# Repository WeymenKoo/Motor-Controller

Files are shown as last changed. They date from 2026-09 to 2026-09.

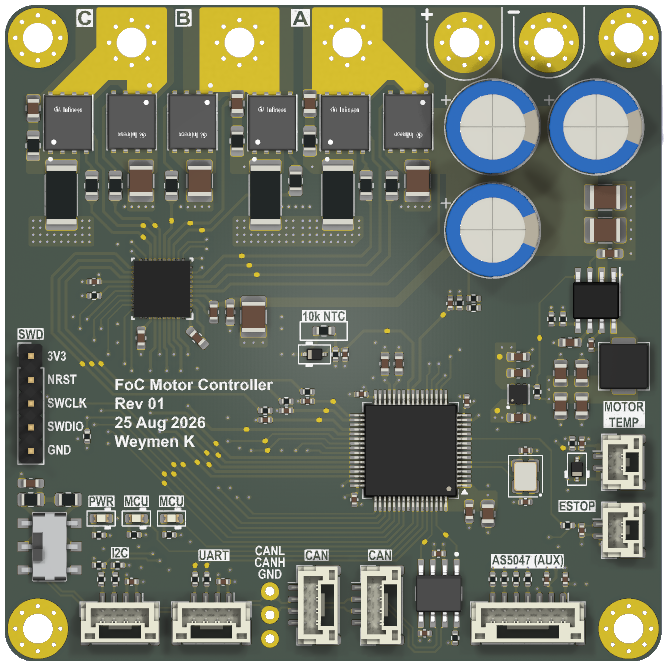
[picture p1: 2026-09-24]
Documentation/FoC Motor Controller Top.png

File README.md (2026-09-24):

# Building a FOC Motor Controller for a Cat-Scale Robot Leg

Technical notes from a full design cycle: idea → theory → schematic → simulation → layout → fab → bring-up plan. Written as a knowledge refresher as much as a build log, so each section starts with the background needed to follow the decision.

**Status:** Rev 1 design-frozen and fabricated. Not yet bench-validated. Everything below is analytical or derived from the fabrication files.

## Repository layout

| Path | Contents |
|---|---|
| `FoC Motor Controller.kicad_pro` / `.kicad_sch` / `.kicad_pcb` | KiCad 10 project, root sheet and board |
| `Schematics/` | Hierarchical sheets (power, MCU, gate driver, MOSFETs, sensing, CAN-FD, interconnects, ...) |
| `Libraries/` | Project-local symbols, footprints and 3D models (referenced via `${KIPRJMOD}/Libraries/`) |
| `Documentation/` | Design rationale, layout/manufacturing review, board renders, RevC action summary |
| `Simulation/` | LTspice inrush and inverter/gate-drive benches |
| `Project Outputs/` | BOM, pick-and-place, netlist, fabrication package (Rev 1), schematic PDF |

Open `FoC Motor Controller.kicad_pro` in KiCad 10. Vendor datasheets and the KiCad worksheet templates are not included in this repo; without the templates KiCad falls back to its default title block.

---

## 1. What and why

A single-axis field-oriented-control motor controller for one joint of a cat-scale bipedal robot. Six boards, one per joint, sharing a 12S bus, coordinated over CAN-FD.

The actuator architecture is **quasi-direct drive** — a low gear ratio (roughly 6:1 to 10:1) between a large-diameter pancake outrunner and the joint, rather than the 100:1+ of a conventional servo.

Why that matters, because it drives everything downstream:

| QDD property | Consequence for the electronics |
|---|---|
| Backdrivable, low reflected inertia | Torque control fidelity matters more than peak power. Current-sense accuracy becomes a first-class requirement, not an afterthought. |
| Joint torque ∝ motor current, almost directly | Current sense error *is* torque error. No gearbox to hide it behind. |
| Impacts transmit straight back to the motor | Regeneration is routine, not exceptional. Bus transient behaviour is a safety question. |
| It hangs on a limb | Board mass is a real constraint. An over-specified power stage is a defect, not free margin. |

Reference motor: ODrive M8325s, 100 KV, 92 mm pancake outrunner, **20 pole pairs**. That pole count comes back repeatedly.

---

## 2. Theory refresher: why FOC at all

### 2.1 The problem with six-step commutation

Trapezoidal (six-step) BLDC control energises two phases at a time and commutates on Hall transitions. It's simple, and for a fan or a drill it's fine. It has two properties that kill it for a leg joint:

- **Torque ripple.** Torque varies by roughly 13% across each 60° electrical sector because the current vector jumps in discrete steps rather than rotating smoothly.
- **No control of the current *angle*.** You can only control magnitude.

### 2.2 What FOC actually does

FOC transforms the three phase currents into a rotating reference frame locked to the rotor, so that a spinning three-phase AC problem becomes two DC quantities you can put a PI loop around.

```
Clarke:  3-phase (a,b,c)  →  2-axis stationary (α,β)
Park:    stationary (α,β) →  rotor-synchronous (d,q)   [needs rotor angle θ]

  i_d  = flux-producing current   → command 0 for a surface-PM motor
  i_q  = torque-producing current → this is your torque command
```

Two consequences worth internalising:

1. **Park needs θ.** The whole scheme collapses without an accurate rotor angle. This is why position sensing is not a peripheral feature — it is load-bearing.
2. **Commanding `i_d = 0`** means all current produces torque and none produces useless flux. That's the efficiency win over six-step, alongside the smoothness win.

The inverse path (inverse Park → SVM → gate signals) synthesises the voltage vector. **Space Vector Modulation** is worth knowing as the standard choice: it uses the two adjacent active vectors plus zero vectors, and by injecting a common-mode third harmonic it gets ~15% more bus utilisation than sinusoidal PWM for the same DC link.

### 2.3 Why sensorless was ruled out immediately

Sensorless FOC estimates θ from back-EMF. Back-EMF is proportional to speed, so at zero speed there is nothing to observe. A leg joint's primary duty is **holding position and torque at or near zero speed** — exactly where the observer has no signal.

Not a close call. Absolute magnetic encoder, AS5047P, 14-bit, over SPI.

**Refresher — magnetic encoder basics:** a diametrically-magnetised magnet on the shaft end, Hall array on the IC, sensing field *direction* not strength. Field strength only has to be in range (typically 30–70 mT). Absolute means it knows the angle at power-up with no homing move — essential when powering up a leg that is already loaded.

---

## 3. Requirements, and one I got wrong in my own documentation

```
Bus:              12S LiPo — 50.4 V full charge, 44.4 V nominal, 56 V max
Phase current:    10 A RMS continuous
Control:          sensored FOC, three-shunt low-side sensing
Comms:            CAN-FD, 6 nodes on a shared bus
Switching:        inaudible
```

### The f_sw story — worth reading as a lesson in post-hoc rationalisation

**The actual requirement was "inaudible."** 40 kHz was chosen as arbitrary headroom above the ~20 kHz audibility limit. That's it.

Later documentation in this project (including my own design record) presented a derivation:

```
f_electrical = rpm/60 × pole_pairs = 3500/60 × 20 ≈ 1167 Hz
20 PWM cycles per electrical cycle → ~23 kHz floor
∴ 40 kHz
```

That derivation is *correct arithmetic* and a genuinely useful sanity check — it confirms 40 kHz is comfortably above the control-bandwidth floor. But it is **not why the number was chosen**, and writing it up as though it were makes the design look more derived than it was.

Worth flagging because this is a common failure mode in engineering documentation: a number picked by judgement acquires a derivation after the fact, and three revisions later nobody remembers which constraint is real. If f_sw ever needs to move, the binding constraint is audibility and the charge-pump budget — not the pole-pair math.

**The 20-cycles-per-electrical-cycle rule** is still worth knowing: it's a sampling-rate argument. Your current loop runs at f_sw, and it has to track a sinusoid at f_electrical. Fewer than ~10–20 samples per cycle and the loop can't keep up with the rotating vector.

---

## 4. Design workflow

Fixed order, applied per subsystem:

```
1. First principles      → napkin numbers, identify the BINDING constraint
                           (no optimisation — the goal is order of magnitude)
2. SPICE                 → build from the napkin result, optimise here
3. Component search      → real parts, availability checked before committing
4. Power & thermal       → hot Rds(on), not the 25 °C headline
5. BoM consolidation     → once the design is stable, never during
6. Schematic review      → verify earlier action items actually landed
7. Layout
```

### Why LTspice is not used for the control loop

Tried it, abandoned it. The timescale separation is fatal:

```
Device switching:      ~5 ns edges
Mechanical settling:   ~500 ms
Ratio:                 10^8
```

A transient solver forced to resolve nanosecond edges across a mechanical settling time isn't just slow — it accumulates numerical error that swamps the result. **Control loops belong in discrete-time simulation. SPICE is for the power stage only.**

Three benches that were useful:

- `dpt_halfbridge.cir` — double-pulse test, one half-bridge
- `input_stage_transients.cir` — hot-plug and inductive transient
- `bus_regen_cascade.cir` — multi-board shared-bus regeneration

**Refresher — the double-pulse test (DPT)** is the standard method for characterising switching loss and overshoot. Two gate pulses: the first builds current in an inductive load, the gap measures turn-off, the second measures turn-on with the current already established. It isolates switching behaviour from conduction behaviour.

The single most useful result from the whole simulation effort:

```
Commutation loop inductance → V_GS undershoot
   2 nH  →  ~0 V
  80 nH  →  −4.9 V
```

Gate-oxide stress and false turn-off appear **well before** drain overshoot looks alarming on a scope. That reframed loop area as the number one layout variable, not one of several.

---

## 5. Power stage

### 5.1 Refresher: where the losses come from

```
Conduction:   P = I²_rms × R_DS(on, hot)
Switching:    P = ½ × V_bus × I × (t_r + t_f) × f_sw
```

Two things that trip people up:

**R_DS(on) roughly doubles from 25 °C to 150 °C.** The datasheet headline is at 25 °C. Using it for thermal work underestimates conduction loss by 2×.

**t_r and t_f are set by gate charge, not by the FET's "speed".** Specifically by **Q_gd**, the gate-to-drain (Miller) charge. During the Miller plateau, all your gate current goes into discharging C_gd while V_DS swings — that's the transition, and that's where switching loss happens.

```
t_r ≈ Q_gd / I_drive
```

So a "faster" FET is one with lower Q_gd, and drive current is a lever you control.

### 5.2 The 40 V mistake

Rev A used CSD18540Q5B — **40 V V_DS rating on a bus whose full-charge voltage is 50.4 V**.

Not a margin question. The device is outside its absolute maximum at rest, before anything switches.

How it happened: component selection was anchored on R_DS(on) and package, with no explicit voltage-margin gate. The rule adopted afterwards:

> **Voltage rating is checked first, against worst-case bus transient, before any other parameter is considered.**

### 5.3 The loss inversion — the most instructive result in the project

Having fixed the voltage rating, the obvious next move is the lowest R_DS(on) 100 V part available. That's how IPT015N10N5 (1.5 mΩ) entered the design.

Running the numbers at the actual operating point:

```
40 A RMS, 40 kHz, 50 V bus, I_drive = 1 A

R_DS(on)   P_cond    P_sw     P_total
1.50 mΩ    1.80 W    3.85 W   5.65 W   ← lowest Rds(on), WORST total
2.24 mΩ    2.69 W    1.58 W   4.27 W   ← best
2.70 mΩ    3.24 W    1.36 W   4.60 W
```

The 1.5 mΩ part loses because its Q_gd is 2–3× higher. **At this current and frequency, switching loss dominates conduction loss**, so the parameter everyone markets on is the wrong one to optimise.

Selection metric changed to **figure of merit**:

```
FOM = R_DS(on) × Q_g     (lower is better)
```

This is the standard metric for exactly this reason — it captures the fundamental process trade-off. A die that's bigger has lower resistance and more gate capacitance. FOM measures how good the silicon is, independent of how you sized the die.

### 5.4 Final selection

**Infineon ISC030N10NM6** (OptiMOS 6), 100 V, 3.0 mΩ max, Q_g 55 nC, Q_gd 14 nC, **PG-TDSON-8 (5 × 6 mm)**.

Note on package: earlier project notes say TOLL. The **fabricated board uses TDSON-8, the 5 × 6 mm package** — that change was made deliberately. Six TOLL packages would occupy roughly 700 mm² for a stage dissipating under a watt at the design point. On a limb, board area is mass, and mass is what the whole machine is fighting. Margin that costs nothing is worth keeping; margin that costs the primary system constraint is a defect wearing a reassuring disguise.

Sourcing note: **JLCPCB's entire 100 V TOLL inventory is optimised for 200–360 A battery/BMS applications.** Those parts buy R_DS(on) this design doesn't need by paying gate charge it can't afford (165–252 nC vs 55 nC). This is a case where local-assembly convenience had to lose to the electrical requirement, and the part became an extended/consigned line.

### 5.5 Thermal

Using hot R_DS(on) ≈ 6 mΩ, datasheet t_r/t_f of 4.5/5.3 ns, R_thJA = 50 °C/W (datasheet figure for ~6 cm² copper, no heatsinking), T_a = 40 °C:

| Phase current | P_cond (3 legs) | P_sw (6 FETs) | P per FET | T_j |
|---|---|---|---|---|
| 10 A | 1.80 W | 0.71 W | 0.42 W | 61 °C |
| 20 A | 7.20 W | 1.41 W | 1.44 W | 112 °C |

**At 10 A the inverter is thermally uncritical.** That's what makes the package downsize a real trade rather than a risk. See §11.2 for how the as-built layout changes the 20 A number.

---

## 6. Gate drive

### 6.1 Refresher: what a gate driver actually has to do

A high-side N-channel MOSFET's source sits at the switch node, which swings to the full bus voltage. To hold it on, V_GS must be ~10 V **above** the switch node — i.e. above the bus. That voltage has to come from somewhere.

Two standard approaches:

- **Bootstrap** — a capacitor charged through a diode while the low side is on. Cheap. Fails at 100% duty cycle because the cap never gets recharged.
- **Charge pump** — an on-chip doubler generating a rail above V_M continuously. Works at any duty cycle.

The DRV8323 has an integrated charge pump. That matters for FOC because SVM does spend time at very high duty on individual phases.

### 6.2 The charge pump budget — and a correction to my own analysis

The charge pump supplies the **high-side** gates only (low-side gates are driven from an internal linear regulator off V_M). TI's datasheet gives:

```
I_VCP ≥ 3 × Q_g × f_PWM        [3 high-side gates]
```

At 55 nC and 40 kHz:

```
I_required = 3 × 55 nC × 40 kHz = 6.6 mA
I_available = 25 mA
Margin = 3.8×                                 ✓ comfortable

Q_g ceiling at 2× margin = 25 mA / (2 × 3 × 40 kHz) ≈ 104 nC
```

**Correction to earlier project documentation.** A design record I wrote during this project claimed the correct 2×-margin ceiling was ~52 nC, derived from `6 × Q_g × f_sw` — counting all six devices. That is wrong: the low-side gates are not a charge-pump load. The original project note (~100 nC at 2× margin) was right and my "correction" introduced an error.

The lesson generalises: **when you re-derive someone's number and get a different answer, check whether you changed the model before concluding they were wrong.** A factor-of-two disagreement is usually a definition disagreement, not an arithmetic one.

Separately, the capability figure itself was corrected in the other direction: an early note said the charge pump supplies 10–15 mA. That's the low-V_M figure where the doubler is strained. At a 44–50 V bus it's **25 mA**.

### 6.3 Slew rate control: gate side, not drain side

**Refresher on the trade.** Fast switching = low switching loss, but high dv/dt and di/dt, which means more overshoot (`V = L·di/dt` across the commutation loop inductance) and more EMI. Slow switching is the opposite. You need a knob.

Three ways to get one:

| Approach | How it works | Verdict here |
|---|---|---|
| Drain-source RC snubber | Damps the loop-L / C_oss resonance | Rejected — costs board area, burns power continuously, and needs resistor power-rating work |
| Asymmetric gate network (R + parallel diode) | Slow turn-on, fast turn-off | Rejected — this is a workaround for drivers with a single fixed drive current |
| Programmable I_DRIVE | Driver sources/sinks a configured current | **Selected** |

The DRV8323's Smart Gate Drive provides independently programmable source and sink currents over SPI — the same asymmetry the diode network provides, implemented internally. TI's own app note recommends a single small or 0 Ω external series resistor when it's in use.

Sizing:

```
I_DRIVE = Q_gd / t_r_target = 14 nC / 50 ns = 280 mA
```

Shipped configuration: **0 Ω series gate resistors populated** (so I_DRIVE has sole control), with the gate-source RC network (3.9 Ω + 2.2 nF per FET) **fitted as DNP footprints**. That's deliberate insurance — ship with the simplest arrangement, add damping only if the real waveforms demand it.

One thing to know if you populate them: a 2.2 nF gate-source cap adds ~22 nC per device to the charge-pump demand (`Q = C·V`). Re-check the budget before doing it.

**Honest caveat:** this replaced a *sized* snubber with a *removed* snubber. That converts a sizing task into a validation task, and it raises rather than lowers the priority of the DPT work. The board has no drain-side snubber footprints, which in hindsight should have been added as DNP.

### 6.4 Dead time

**Refresher:** both FETs in a leg on simultaneously = shoot-through = a direct short across the bus through two devices. Dead time is the deliberate gap where both are off.

```
t_dead > t_r + t_f + driver propagation delay mismatch
```

Start conservative (200–300 ns), measure, reduce. It's SPI-programmable, so it's a bench task, not a design-time commitment. Note that the datasheet's 4.5/5.3 ns figures are quoted at R_g = 1.6 Ω, which is *not* this gate network.

---

## 7. Current sensing

### 7.1 Refresher: the three topologies

| Topology | Pros | Cons |
|---|---|---|
| **Low-side shunt** | Ground-referenced, cheap, simple amplifier | Blind at very high duty cycle; measures leg current not phase current |
| **In-line phase** | True phase current at any duty | Needs high-common-mode or isolated amps; expensive |
| **High-side** | Sees bus current | Common mode at bus voltage |

Chose **three low-side shunts** into the DRV8323's integrated CSAs. Three rather than two: the third gives redundancy and a consistency check (`i_a + i_b + i_c = 0`) rather than requiring reconstruction.

### 7.2 The thing that actually determines whether it works

Not the filter. **Sample timing.**

Low-side shunt current is only valid while the low-side FET is on. During switching transients it's garbage. The fix is to sample at the **centre of the PWM period**, where all three low sides are on and the transients have settled:

```
Centre-aligned PWM → TIM1_TRGO2 at the counter peak → triggers ADC
```

The RC filter on the sense lines (56 Ω + 2.2 nF, f_c ≈ 1.29 MHz, τ ≈ 123 ns) is **edge damping and ADC input protection, not switching-noise rejection**. At 40 kHz it attenuates nothing. Its job is to be settled by the time the sample fires — 10τ ≈ 1.23 µs of margin.

> Filtering cannot substitute for correct sample timing. If your currents are noisy proportional to duty cycle, move the trigger; don't add capacitance.

### 7.3 Shunt and gain are one decision

```
Full scale = (V_ref / 2) / (G × R_shunt)

3 mΩ, G=20  →  ±27.5 A    ✓ selected
3 mΩ, G=40  →  ±13.75 A   ✗ below peak current
5 mΩ, G=20  →  ±16.5 A    ✗ only 1.17× over the 14.1 A peak
5 mΩ, G=10  →  ±33 A      — the earlier frozen value
```

Resolution at the shipped config: **~13.4 mA/LSB**. Dissipation: 0.3 W each at 10 A, 1.2 W at 20 A, in a 3 W part.

**Refresher — Kelvin sensing.** A 3 mΩ shunt develops 30 mV at 10 A. A few mΩ of trace or solder-joint resistance in the sense path is a large fraction of that. Kelvin (4-wire) connection taps the sense voltage at the resistor body itself, carrying no power current. Implemented here with net ties on the sense pads.

### 7.4 A retracted instruction worth recording

An action item carried forward for several revisions said: **change the shunts from 5 mΩ to 1 mΩ, critical.**

It was generated during a MOSFET-selection exercise at a **40 A RMS** operating point, where 5 mΩ would dissipate 8 W in a 3 W part. Entirely correct there.

At the frozen 10 A design point it's unnecessary and actively harmful — it throws away a factor of five in sense resolution for no thermal benefit.

> **An action item carried forward without its operating-point context is worse than no action item.** Every carried item should state the assumption it depends on.

### 7.5 Overcurrent protection: know what's actually protecting you

Two mechanisms exist on the DRV8323:

- **SEN_OCP** — threshold across the sense resistor. At 3 mΩ this implies a trip current in the hundreds of amps. **Unusable.**
- **VDS_OCP** — measures V_DS across the conducting FET.

```
VDS_LVL = I_trip × R_DS(on, hot)
        = 20 A × 6 mΩ = 120 mV
```

Even configured well, hardware OCP sits far above the working range (on the order of 80 A+ against ~10 A operation). The practical consequence:

> **In normal operation, firmware current limiting is the only real protection.** Hardware OCP is a catastrophe backstop — shorted phase, shorted FET — not a current limit. The firmware limit must be robust, because nothing underneath it will catch a 15 A overcurrent.

---

## 8. Power tree, and a scope decision

### 8.1 The cut that mattered most

Early revisions carried a full input-protection front end on the controller board: LM5069 hot-swap controller, back-to-back SOA-rated pass FETs, inrush limiting, UVLO/OVLO, current limit, latch-off.

**That was removed.** Input protection and hot-swap are delegated to a dedicated upstream **Power Distribution Board (PDB)**, shared across all six joints.

This is the right architectural call and it's worth stating why:

- Hot-swap protection is a **bus-level** function. Six copies of it is six times the mass and cost for a job that only needs doing once, at the point where the bus meets the battery.
- The hardest constraints (SOA-rated pass FETs, inrush energy into 500 µF, latch-reset access) get easier when there's one of them in an accessible place instead of six buried in limb segments.
- It removed roughly a dozen line items and a significant chunk of board area from every joint.

Alongside it, the board also runs **bench-powered** during lab work — which is the correct way to bring up a prototype anyway.

What stayed on-board: a local TVS clamp (SMCJ51CA). Local transient clamping is still a board-level responsibility.

### 8.2 The remaining power tree

```
+VPROT (36–56 V) → LMR36520 buck (400 kHz) → +5 V
                                            → TLV75733 LDO → +3V3
```

Two converters. Simple, and defensible: a single-stage 50 V → 3.3 V buck runs at a tiny duty cycle with poor transient behaviour, and the 5 V rail is needed anyway for the CAN transceiver and connector supply pins.

### 8.3 The pre-boot window

**Refresher on why this matters more than power-up ordering.** No sequence of rails coming up will destroy anything here. What sequencing actually buys you is the guarantee that **the gate driver is never live and armed while the MCU's PWM state is undefined**.

+VPROT is live for tens of milliseconds before the MCU boots. During that window:

```
REQUIRED: external 10 kΩ pulldowns on DRV_ENABLE, DRV_CAL,
          and all six INHx/INLx.
```

The driver's internal 100 kΩ pulldowns are too weak to rely on against flux residue, probing, or partial population. A floating CAL pin can put the amplifiers into calibration mode at power-up.

Also: `nFAULT` and `nSCS` pull-ups must go to the **main 3.3 V rail**, never to the driver's own generated DVDD — which dies whenever the driver is disabled, exactly when you most want to read the fault line.

### 8.4 Power-down ordering works in your favour

```
DRV8323 V_M UVLO ≈ 6 V
Buck operates down to a much lower input
```

On bus collapse, **gate drive dies before logic does**. That window is what lets the MCU log the fault and emit a CAN frame. Put fault reporting early in the brown-out handler and you get a free post-mortem.

### 8.5 An open finding: no separate analog rail

In the fabricated Rev 1, **VDDA, VREF+ and the DRV8323 VREF all sit on the raw +3V3 digital rail.**

**Refresher on why that's not ideal.** The ADC reference sets the absolute scale of every measurement. A 12-bit converter on a 3.3 V reference has 1 LSB = 806 µV. An LDO gives maybe 40 dB of rejection at 100 kHz and only 10–20 dB by 1 MHz, so switching ripple reaching the rail translates directly into reference wander — ~10 mV of ripple is ~12 LSB, more than the converter's own unadjusted error budget.

Rev 2 fix: ferrite bead plus local caps to create a separate `+3V3A` node.

Partial mitigation that already exists: **current sense is ratiometric** through the DRV8323's own VREF, so CSA gain error largely cancels. Bus voltage and temperature sensing are *not* ratiometric and inherit the LDO's absolute accuracy directly.

---

## 9. Communications

### 9.1 CAN-FD

Convergent choice across every comparable open-source design (ODrive, moteus). Deterministic multi-drop on a six-node bus, enough payload for command + telemetry, two-wire harness that suits a limb.

**Refresher — split termination.** Standard CAN termination is 120 Ω across the pair at each end of the bus. *Split* termination divides it into 2 × 60.4 Ω with a capacitor (47 nF here) from the midpoint to ground. The differential impedance is unchanged; the capacitor gives common-mode energy somewhere to go.

```
Common-mode path: 30.2 Ω × 47 nF → f_c ≈ 112 kHz
```

**Termination topology is a system-level property, not a board property:**

```
6 nodes, each with 120 Ω fitted  →  20 Ω bus  →  does not work
Correct: exactly 2 terminators, at the two PHYSICAL ends
```

So termination must be selectable per board while keeping every board identical. On this layout the split network (R45/R46/C68) sits clustered with **SW1**, a DPDT slide switch — a DPDT being exactly what you need to bring both lines into termination.

### 9.2 Oscillator tolerance — the constraint people miss

**Refresher.** CAN has no separate clock line. Receivers resynchronise on edges, and the tolerance budget has to accommodate *both* nodes' clock error. CAN-FD's data phase is faster and the budget is correspondingly tighter.

```
Ceramic resonator:  ±0.5%  = ±5000 ppm
Quartz crystal:     ±30 ppm typical
Ratio:              ~170×
```

A ceramic resonator is marginal for classical CAN and generally insufficient for CAN-FD data-phase bit timing. Swapped to quartz. Cost: about 35 cents and two load capacitors.

There was no competing constraint because native USB was dropped (see §10), so the crystal only serves the timer and CAN clock trees.

### 9.3 Node addressing — an idea that came and went

Six physically identical boards need to be distinguishable **without reflashing**, and a board swapped in the field should take on the identity of the joint it's installed in. So the ID must be in hardware.

**Approach 1 — binary-weighted resistor ladder into one ADC pin.** Four jumpers, 16 addresses, one pin instead of four GPIO.

```
V_node = 3.3 / (1 + n)      where n = binary sum of closed jumpers

code 0  → 3.300 V
code 1  → 1.650 V
code 7  → 0.413 V
code 15 → 0.206 V
```

Two engineering notes on this that are generally useful:

- **The response compresses at high codes.** Gap between codes 14 and 15 is ~13.75 mV. That forces 1% resistors, oversampling, and a boot-time-only read — all required, not optional.
- **Source impedance hits 100 kΩ at code 0**, which demands the maximum ADC sampling time. Fine, because it's read once before PWM is active, so switching noise is absent entirely.

The ladder was built from **parallel combinations of values already on the board** (2 × 100 kΩ = 50 kΩ for the 49.9 kΩ leg; 2 × 24.9 kΩ = 12.45 kΩ for the 12.4 kΩ leg) — a BoM consolidation trick that trades two extra placements for two whole line items, with a 0.2–0.4% shift that is invisible against 16-level quantisation.

> Worth recording: when I first reviewed this network I misread the parallel pairs as a broken ladder and flagged it as an error. It wasn't. **Parallel/series synthesis from existing values is a legitimate and underused consolidation technique**, and a reviewer who doesn't recognise the pattern will call it a mistake.

**Approach 2 — GPIO solder bridges.** Simpler, no analogue decode, at the cost of pins.

**What actually shipped: neither.** Rev 1 has no node addressing mechanism. It's a Rev 2 item. Noting it honestly because the design record spent real effort on a feature that didn't make the board.

---

## 10. Scope discipline: what got deleted

Roughly as much engineering went into removing things as adding them. The pattern worth extracting: **re-check why a part is there, not just whether it works.**

| Removed | Why it existed | Why it went |
|---|---|---|
| LM5069 hot-swap front end | Inrush, UVLO/OVLO, fault current limit | Bus-level function → moved to the PDB |
| USB-C + CH340X UART bridge | Config and console access | SWD/RTT does the same job with no extra silicon, no connector, and no boot-select pin conflict |
| Gate network diode (R + parallel D) | Asymmetric turn-on/turn-off | DRV8323 IDRIVEP/IDRIVEN does it internally |
| LED buffer MOSFETs | 5 V / 3.3 V level mismatch | Mismatch disappeared when LEDs moved to the 3V3 rail; 3.9 mA is well inside a 20 mA GPIO |
| Encoder UVW output | Commutation fallback | ABI retained; UVW added pins for a mode not used |
| Qwiic connector | Expansion | Lost to MCU pin constraints |
| Node ID resistor ladder | Hardware addressing | Deferred to Rev 2 |

Two of these — the gate diode and the LED buffers — were **not wrong when added**. They both outlived their justification. Neither would have been caught by "does this work?"; both were caught by "why is this here?"

---

## 11. Layout

### 11.1 Refresher: the three things that matter

**1. Commutation loop area.** The loop is `bulk cap → high-side FET → switch node → low-side FET → ground → back to cap`. Its inductance rings against the FETs' C_oss at every switching edge. Per the DPT result in §4, gate ringing gets dangerous before drain overshoot gets visible.

**2. Return current paths.** High-frequency return current does **not** take the shortest path — it takes the path of lowest impedance, which means it flows directly under the signal trace on the nearest plane. A slot or split in that plane forces it to detour, which increases loop area and radiates. This is why an unbroken plane beats a carefully-drawn split almost every time.

**3. Ground domain separation where the silicon asks for it.** The DRV8323 provides separate AGND (pin 32) and PGND (pin 40). Honouring that in copper — joined at **one star point at the shunts** — is mandatory. Merging them anywhere else injects CSA offset error, which corrupts current feedback and therefore torque control directly.

> These last two look contradictory until you see the distinction: **a split defined by the silicon at a defined star point is a different operation from a split the designer invented.** Don't slot a plane; do honour a device's documented ground pin separation.

### 11.2 What the fabricated board actually shows

Verified from the gerbers, drill files and IPC-356 netlist.

**Board:** 70.1 × 70.1 mm, 6 layer. Stackup `Sig/Pwr · GND · Sig/Pwr · Sig/Pwr · GND · Sig/Pwr`.

**What's right:**

- **L2 and L5 are perfect** — solid, unbroken ground planes across the whole board, nothing but via antipads. No splits, no routing, no slots. Under the power stage specifically.
- **High-side FET drains have 16 via-in-pad each** (4×4 grid, 0.25 mm) against the ≥9 specified.
- **Every thermal pad is windowpaned on the stencil** — 15 apertures on the FET drains, none over 3 mm². This is the difference between a flat joint and a floating part.
- **Power in and phases out share one board edge**, immediately adjacent to the FET row.
- **Single-point chassis bond implemented correctly**: four mounting holes each with a 0 Ω and a 1 nF/1 kV footprint; only **one** 0 Ω populated, three 1 nF fitted. One DC bond defines chassis potential; a second would create a ground loop through the cable shields.

**The one real finding:**

```
High-side FETs (Q3/Q5/Q7):  16 thermal vias each → inner-layer spreading
Low-side FETs  (Q4/Q6/Q8):   0 vias
Switch nodes OUT_A/B/C:      0 vias anywhere
```

Keeping the switch nodes entirely on L1 is a **defensible EMI choice** — no switching copper on inner layers, no via stubs on the noisiest nets. But it means the low-side devices dissipate into roughly 80–100 mm² of top copper, against the ~600 mm² the 50 °C/W datasheet figure assumes.

Revised estimate (R_thJA ≈ 75 °C/W, scaled — needs bench verification):

| Phase current | P per FET | T_j estimated | Earlier claim |
|---|---|---|---|
| 10 A | 0.42 W | **72 °C** ✓ | 61 °C |
| 20 A | 1.44 W | **148 °C** | 112 °C |

**At 10 A this is fine. The 20 A claim does not survive the as-built thermal path** — margin to the 175 °C limit drops from ~63 °C to ~27 °C, before counting the shunt's 1.2 W right next to it. Treat 10 A as the rating until measured.

**Other findings:**

- **Board NTC sits at board centre** — 22 mm from the FET array, directly above the encoder whose self-heating it partly reads. It's the coolest point on the board. A calibration problem rather than a defect: characterise the offset against a FET-case thermocouple and bake it into the trip threshold.
- **No fiducials on the top layer.** Finest pitch is 0.5 mm (DRV8323 WQFN-40, STM32 LQFP64). Assembly houses normally add panel fiducials, which is usually adequate at that pitch, but locals are standard practice.
- **No reference designators on silkscreen** — functional labels only. Fine for machine assembly, awkward for hand rework, and it matters more for a board other people will build.

### 11.3 On bulk capacitor placement, and a number worth checking before "fixing" it

Two of the bulk capacitors sit 20–45 mm from the furthest half-bridge. That looks alarming until you check the frequency:

```
At 40 kHz:  X_L of 40 nH ≈ 10 mΩ
            Capacitor ESR ≈ 35 mΩ
```

The interconnect inductance barely affects ripple sharing. The **high-frequency commutation loop is closed by the MLCCs 6 mm from the FETs**, not by the bulk bank. The placement is correct.

Recording it because it's exactly the kind of thing a later revision "fixes" by someone who didn't run the numbers.

### 11.4 Bulk capacitance: sized by ripple current, not capacitance

**Refresher.** The DC link capacitor's job in an inverter isn't primarily energy storage — it's supplying the high-frequency component of inverter current so the battery and its wiring don't have to. The binding spec is usually **RMS ripple current capability**, which is a thermal limit (self-heating via ESR), and which scales with the can's surface area.

```
Capacitance requirement:      met by 3 pieces (~322 µF effective)
Ripple current requirement:   ~7.8 A
  3 × polymer → 7.5 A capacity  → ~96%, overloaded
  5 × polymer → 12.5 A          → the minimum defensible count
```

The design was frozen at five. **Three were built.** A longevity issue rather than a bring-up one — running at or above the ripple rating shortens life through self-heating rather than failing immediately. Measure actual ripple per capacitor before any production run.

Also worth knowing: **MLCC effective capacitance collapses under DC bias.** A 4.7 µF X7R at 50 V may deliver ~40% of nameplate. The MLCC bank here contributes only ~7–10% of ripple current after derating — its job is **ESL reduction at the half-bridge inputs**, and it must not be counted toward reducing the polymer count.

---

## 12. Manufacturing notes

### 12.1 Via-in-pad — the item most worth checking

Each high-side FET drain has **16 open 0.25 mm vias inside a 4.41 × 3.73 mm solder pad**, with a single mask opening covering the whole pad.

**Refresher on why that's a problem.** During reflow, molten solder wicks down open via barrels by capillary action. Consequences in order of severity:

1. **Voiding under the thermal pad** — destroying the exact thermal path the vias exist to create
2. Solder balls on the bottom side
3. Component tilt or opens as solder depletes unevenly

The fix is a fab option, not a gerber change: **resin-plugged and copper-capped via-in-pad (POFV)**. Verify it was ordered. If not, X-ray a first article at the FET pads before powering anything.

### 12.2 Things gerbers don't tell you

- **Copper weight is an order parameter.** Nothing in a gerber records it. Every thermal and current figure assumes 2 oz outer; at 1 oz the phase conductors carry roughly half the current for the same rise.
- **L1↔L2 dielectric thickness** sets the return-path loop area for every switching edge on the top layer. Worth confirming rather than assuming.

### 12.3 Via geometry

Used 0.25 mm drill on 0.55 mm pad = **0.15 mm annular ring**. JLCPCB advises ≥0.15 mm to mitigate drill breakout — so exactly on the line, with no margin for registration error on a 6-layer lamination. 0.3/0.6 mm costs nothing and buys the margin back.

### 12.4 BoM consolidation techniques

Done **once the design was stable**, never during. Early consolidation biases component choices for the wrong reason.

| Technique | Example |
|---|---|
| Merge duplicate rows | Same part number split across two BoM rows |
| Parallel synthesis | 49.9 kΩ from 2 × 100 kΩ already on the board |
| Series synthesis | 37.3 kΩ from two existing values — which also fixed a working-voltage violation |
| Footprint substitution | Zero-ohm links moved to a size already in use |
| Dielectric upgrade | X5R → X7R (X5R is only characterised to 85 °C — a real derating risk next to a six-FET bridge) |

Equally important, what was **declined**: trip-point dividers (synthesis lands 2.5% off, directly on a threshold), USB-C CC pull-downs (value mandated by spec), gate resistors (value set by dv/dt work, not economics), and high-voltage divider legs kept as series pairs specifically so no single 0402 exceeds its ~50 V working-voltage limit.

> **Consolidation stops where the reason the part was chosen begins.**

### 12.5 A consequence that must propagate

Two accepted changes altered divider ratios, which changes **firmware scaling constants**. The bus-sense lower leg moved from 2.2 kΩ to 2 kΩ.

This is exactly the class of change made for BoM reasons that silently breaks a calibration constant nobody re-derived. Recalibrate against a measured bus voltage at bring-up — 1% resistor tolerance alone gives ~32 LSB of absolute error.

---

## 13. Firmware constraints baked into the hardware

Three that will cost days if discovered at bring-up rather than read here first.

### 13.1 UCPD dead-battery pulldowns

PB6 and PB4 carry internal 5.1 kΩ pulldowns associated with the USB-C controller. Those pulldowns are **enabled by a high level on PA9/PA10** — which on this board are two of the high-side PWM outputs.

```
Consequence: starting TIM1 pulls down a UART line and an LED line.
REQUIRED:    set PWR_CR3.UCPD1_DBDIS = 1 BEFORE enabling TIM1.
```

Symptom if you miss it: an LED that glows faintly and permanently once the motor timer starts.

This one was found, fixed by pin reassignment, and then **reappeared after a later pin shuffle** — which is the argument for putting constraints on the schematic rather than in a changelog.

### 13.2 ADC channel pairing

```
FILTER_SOA → PB11 (ADC1 and ADC2 — shared)
FILTER_SOB → PB12 (ADC1 only)
FILTER_SOC → PB14 (ADC1 only)
```

Dual-simultaneous sampling must always pair SOA on ADC2 with SOB *or* SOC on ADC1. **Phases B and C can never be sampled together.** Reconstruct the third from `i_a + i_b + i_c = 0`.

Permanent, and created by a layout-convenience pin assignment. Worth documenting now rather than discovering during commissioning.

### 13.3 Timer break input

`DRV_nFAULT` lands on PA15 = TIM1_BKIN. Configure it as a **timer break input**, not an EXTI.

**Refresher:** break gives hardware output disable, independent of interrupt latency — the timer drops the outputs in silicon. An EXTI handler is at the mercy of whatever else is running. For a leg joint, automatic output enable (AOE) should be **off**: require an explicit re-arm after a fault.

---

## 14. Safety architecture

### 14.1 Fault state is coast, not brake

**Refresher on why.** Shorting all three low sides brakes the motor by dissipating back-EMF in the phase resistance:

```
At speed: ~19 V back-EMF into ~100 mΩ phase resistance
        ≈ 180 A
```

That exceeds both device and motor ratings. Braking by shorting **must** be current-limited and PWM-modulated, which requires firmware to be alive — so it cannot serve as a hardware backstop.

Fault state is therefore high-impedance: the limb free-falls. If uncontrolled drop is a hazard, that needs a mechanical fail-safe brake, which is outside this board.

### 14.2 Two mechanisms, two timescales

Every open-source reference surveyed (ODrive, moteus, ODRI, OpenPodcar) kept a physical stop independent of the compute path. None used a software stop as the sole mechanism.

The reason is precise: **a level signal tells the board what the controller wants right now, but has no opinion about whether the controller is still alive.** That's the gap a heartbeat closes, and the gap a physical contactor closes when the heartbeat itself can't be trusted.

```
t=0      Signal-level disable → inverter safe in microseconds
t≈500ms  Contactor opens → power removed
```

The 500 ms gap gives every node time to emit a CAN fault frame.

**A tempting wrong answer worth naming:** wiring the e-stop into a hot-swap controller's UVLO pin. It's the pin manufacturers advertise for remote shutdown, and it's wrong here — it removes bus power instantly, dropping the motor to coast in the worst possible way and killing the MCU before it can report anything.

Rev 1 has a 2-pin e-stop connector with proper conditioning (1 kΩ series, RC filter, clamp) routed to a hardware break path. **Verify empirically that an unplugged cable leaves the driver disabled** — that's the fail-safe property, and it's the kind of polarity question that gets flipped for bench convenience and then forgotten.

---

## 15. Bring-up plan

Not yet executed. Staged so each step gates the next.

```
0. Inspect      X-ray a FET drain for wicking voids. Confirm 2 oz copper.
                Visual: FET orientation, cap polarity, connector pin 1.
                Continuity: bus+ to bus− is not a short.

1. Dead board   Current-limited bench supply, 24 V @ 100 mA. NOT a battery.
                Rails: +5 V, +3V3. Draw settles < 50 mA.
                SWD connects, correct device ID.
                E-STOP UNPLUGGED → confirm driver disabled. Record it.

2. Gate driver  UCPD_DBDIS first. Then enable, wait t_WAKE 1 ms.
                SPI read-back of every register you write — never assume.
                CSA offset calibration, motor disconnected.
                Scope one gate pair DIFFERENTIALLY at low duty.

3. IDRIVE sweep BEFORE any high current. 0 Ω gate resistors mean IDRIVE is
                the only slew knob — find the setting before loading it.

4. Double pulse Characterise V_DS overshoot and V_GS undershoot for real.
                This is the measurement the removed snubber owes.

5. Encoder      Field strength in range. Monotonic sweep, one wrap per rev.
                Two wraps = magnet diametric misalignment (mechanical).
                Zero parity errors over thousands of reads.

6. First motion Open-loop current at fixed angle (~1 A) → rotor aligns.
                Confirm i_a + i_b + i_c ≈ 0.
                Encoder-to-phase alignment, repeatable across runs.
                Closed-loop torque at low i_q.

7. Characterise Low-side FET case temp at 10 A — NOT high-side.
                R37 offset vs that thermocouple → NTC calibration constant.
                Encoder angle vs i_q → current-correlated error check.
                Ripple current on one bulk cap.
```

### Measurement technique notes

**Probing.** Use a ground spring, not the alligator lead, for anything above 1 MHz. A 15 cm ground lead adds ~150 nH, which rings with the probe capacitance and produces overshoot *on the screen* that doesn't exist on the board. That will send you hunting a snubber problem you don't have.

**Never ground-reference a high-side gate measurement.** GHx is referenced to SHx, which swings the full bus. Measure V_GS differentially or you'll read the switch node and conclude the gate drive is broken.

**Thermal.** Thermocouple placement plus IR camera with emissivity correction (bare copper and solder mask have wildly different emissivity — IR without correction reads nonsense on a PCB). For R_thJA extraction, the standard method uses **R_DS(on) as the temperature sensor** per JESD51-1: calibrate resistance against temperature in an oven, then infer junction temperature from measured resistance under load. Also watch shunt TCR drift — the current reading itself moves with temperature.

**Encoder angle vs current.** Phase conductors pass ~22 mm from the sensor:

```
B = µ₀I / 2πr = (4π×10⁻⁷ × 10) / (2π × 0.022) ≈ 91 µT ≈ 0.9 gauss
```

Against a 300–700 gauss working field that's 0.15–0.3%, i.e. ~0.1–0.2° of angle error. Small — but **current-dependent and therefore torque-correlated**, so it appears as torque ripple rather than random noise. Compensable in firmware with a current-proportional offset term if it shows up.

---

## 16. Rev 2 list

| Priority | Change | Driver |
|---|---|---|
| 1 | Thermal vias in low-side drain pads, or a bottom-side switch-node pour | §11.2 — the only finding with a real performance consequence |
| 2 | Move the board NTC into the FET zone, or add a second one there | §11.2 — you can't control a temperature measured 22 mm away |
| 3 | Separate `+3V3A` via ferrite + local caps for VDDA/VREF+ | §8.5 |
| 4 | Bulk back to 5 pieces, or a lower-ESR part | §11.4 |
| 5 | Hardware CAN node addressing | §9.3 — never shipped |
| 6 | DNP drain-side snubber footprints | §6.3 — insurance the current board lacks |
| 7 | Fiducials (3 global + locals on the fine-pitch parts) | §11.2 |
| 8 | Reference designators on silkscreen | §11.2 — matters for an open board |
| 9 | Vias to 0.3/0.6 mm | §12.3 |
| 10 | Resolve the TVS clamp vs 65 V abs-max question | Carried open |

---

## 17. Lessons

Generalisable, in rough order of how much they cost to learn.

**Select on the metric that binds, not the metric that's famous.** R_DS(on) is what every MOSFET is marketed on and it was the wrong parameter here. Identifying which constraint actually binds *is* the first-principles stage.

**When you re-derive a number and disagree, check whether you changed the model.** The charge-pump correction in §6.2 was my own error, from counting six gates where the charge pump drives three. A factor-of-two disagreement is usually a definition disagreement.

**An action item without its operating point is a hazard.** The 1 mΩ shunt instruction was right at 40 A and harmful at 10 A. Carried items should state the assumption they depend on.

**Check the note against the symbol.** A gate driver ordering code was wrong in written guidance for several revisions while the schematic symbol was correct throughout. Any fact stored in two places will eventually disagree in two places.

**When the reason for a part evaporates, delete the part.** The gate diode and the LED buffers were both correct when added and both outlived their justification. "Why is this here?" is a different review pass from "does this work?", and worth running explicitly.

**Removing a component is not the same as sizing it.** Deleting the snubber closed a requirement by deletion rather than analysis. That converts a sizing task into a validation task — requirements closed by removal deserve *more* scrutiny, not less.

**Over-provisioning is a cost, not free margin.** Six oversized packages for a stage dissipating under a watt is board area bought to solve a problem that doesn't exist — and on a limb, board area is mass. Margin that costs the primary system constraint is a defect wearing a reassuring disguise.

**The failure that gets you is the connector, not the silicon.** The highest-rated risk in this design was never a semiconductor at 1.2× voltage margin. It was a synchronous serial bus running over an unshielded cable through a moving joint. (Which is why the encoder came back on-board.)

**A number picked by judgement will acquire a derivation.** 40 kHz was chosen because it's inaudible. The pole-pair math came later and is a fine sanity check — but three revisions on, nobody remembers which constraint is real. Write down *why* at the moment you choose, not afterwards.

---

## Appendix: references worth reading

**Gate drive and power stage**
- TI SLVSDJ3D — DRV8323 datasheet (charge-pump equation, generator mode §10.1, layout §12.2.1)
- TI SLVA714 — understanding IDRIVE and TDRIVE
- TI SLVAF66 — motor driver system design; brake vs coast topology
- Infineon OptiMOS 6 / ISC030N10NM6 datasheet

**MCU**
- ST DS12589 — STM32G431 datasheet (I/O structure table; the UCPD dead-battery note)
- ST RM0440 — reference manual (PWR_CR3, timer break, ADC dual injected mode)
- ST AN2867 — oscillator design guide (crystal CL and gain margin)
- ST AN4013 — timer overview (complementary PWM, dead time, break)
- ST AN2834 — getting the best ADC accuracy, including a PCB layout section

**Layout and EMC**
- Henry Ott, *Electromagnetic Compatibility Engineering* — return current paths, mixed-signal layout
- Analog Devices MT-031 — grounding data converters, and the case against splitting planes
- Rick Hartley, *How to Achieve Proper Grounding* — why plane cuts cause more problems than they solve

**Control theory**
- TI BPRA048 — Clarke and Park transforms
- SimpleFOC documentation — FOC theory section, and a practical bring-up reference

**Reference designs**
- ODrive (ODriveHardware, ODrive S1) — closest architectural match
- mjbots moteus — Apache-licensed full KiCad source, CAN-FD servo across several revisions
- ODRI (Open Dynamic Robot Initiative) — distributed actuator architecture, e-stop in the power board

**Standards**
- ISO 11898 — CAN bit timing and oscillator tolerance budget
- IEC 60204-1 — stop categories
- IEC 61800-5-2 — safe torque off terminology
- JESD51-1 — thermal test method (R_DS(on) as temperature sensor)

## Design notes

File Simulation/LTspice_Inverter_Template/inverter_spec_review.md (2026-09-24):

# Design Review — Switching Frequency, and What This Drive Actually Is

Reviewer's assessment from the simulated hardware alone. Part 2 deliberately ignores any stated design target and derives the capability envelope from the components and the sim.

---

# Part 1 — Is 40 kHz needed?

**No. Not for the reason you chose it, and it is not free.**

## Your stated goal is met at 25 kHz with margin

Adult hearing rolls off at 15–17 kHz; 20 kHz is the textbook ceiling and only some children reach it. PWM acoustic energy sits at f_sw and its sidebands at f_sw ± k·f_e. With f_e up to ~1 kHz, 25 kHz puts the lowest sideband at ~24 kHz — inaudible to everyone. 20 kHz would be borderline (lower sideband lands at ~19 kHz); **25 kHz is a sound choice and 40 kHz buys nothing acoustically.**

Three audible mechanisms that f_sw does *not* fix, so don't expect silence from frequency alone:

- Torque ripple at 6× electrical frequency — at 1 kHz electrical that's 6 kHz, loudly audible. This is a FOC quality problem.
- Sub-harmonic limit cycling at f_sw/2 = 12.5 kHz, which is very audible. Runs the risk of appearing if the current loop executes every other PWM cycle. **Keep the current loop at f_sw, not f_sw/2.**
- Mechanical/structural resonance excited by current ripple.

## What 25 kHz actually buys you: about 30 % of your inverter loss

Simulated, IDRIVE 0.57/1.14 A, no snubber, 50.4 V bus, per leg:

| I_rms | 25 kHz | 40 kHz | saving |
|---|---|---|---|
| ~10.6 A | 0.95 W | 1.38 W | **31 %** |
| ~15 A | 1.67 W | 2.36 W | **29 %** |
| ~20 A | 2.61 W | 3.64 W | **28 %** |

Across three legs at 15 A rms that is 5.0 W vs 7.1 W. Switching loss dominates this design, so f_sw is the single biggest lever you have on thermal performance — and thermal is what caps your continuous current rating. **Dropping to 25 kHz directly buys continuous current capability.**

Secondary wins at 25 kHz: the three-shunt sampling window gets easier (min low-side on-time ~1.1 µs is 2.8 % of a 40 µs period vs 4.4 % of 25 µs), and raising dead time to fix the shoot-through margin costs less duty range (300 ns = 0.75 % of period vs 1.2 %).

## What 40 kHz buys: ripple and top-speed control quality

**Current ripple**, single-leg 50 % duty worst case at ~10 A rms:

| L_phase | 25 kHz | 40 kHz |
|---|---|---|
| 15 µH | 18.5 A pp | 15.5 A pp |
| 30 µH | 13.6 A pp | 9.6 A pp |
| 60 µH | 7.9 A pp | 5.1 A pp |
| 120 µH | 4.1 A pp | 2.6 A pp |

A wye 3-phase load sees roughly 1.5× the effective inductance and SVPWM applies fewer volt-seconds, so real ripple is about 0.5–0.7× these figures.

**Top speed.** 20 pole pairs is a lot. At the 5040 RPM no-load point, f_e = 1680 Hz. Good FOC wants f_sw/f_e ≥ 20:

- 25 kHz → f_e ≤ 1250 Hz → **~3750 RPM** usable
- 40 kHz → f_e ≤ 2000 Hz → 6000 RPM (above the motor's no-load speed, so not limiting)

For a QDD leg through any reduction at all, 3750 RPM is far more than you need. This constraint is almost certainly irrelevant to you — but it is the honest answer to "what does 40 kHz buy".

## The decision actually hinges on a number you have not measured

Everything above is secondary to **phase inductance**, which ODrive does not publish for the M8325s and which I could not find anywhere. The 15 µH in the model is a placeholder. Run `odrivetool` calibration — it applies a square wave and measures ripple directly — and use the **phase-neutral** value (most manufacturers quote phase-phase, which is exactly 2×).

Then:

| Measured L_phase | Call |
|---|---|
| **≥ 50 µH** | 25 kHz comfortably. Take the thermal win. |
| **20–50 µH** | 25 kHz, verify ripple is tolerable in current sensing and iron loss. |
| **≤ 20 µH** | Neither frequency fixes it — at 15 µH even 40 kHz leaves ~100 % ripple. The answer is series inductors, or accepting the ripple with eyes open. Do not reach for 40 kHz thinking it solves this. |

**Recommendation: design for 25 kHz, confirm against measured inductance.** If it turns out you need 40 kHz for ripple, you will also need the IDRIVE increase from the previous review to afford it thermally.

---

# Part 2 — What this drive actually is

Written as if I had never seen a requirement for it.

## Headline

**A 48 V-class, ~10–12 A rms continuous, 3-phase FOC servo drive with high-bandwidth torque control and no regenerative energy path.**

The interesting thing about this board is that its *stated* component ratings and its *actual* capability disagree in two places, both worth knowing before anyone writes it on a datasheet.

## Bus voltage — the binding limit is 51 V, not 100 V

| Element | Rating |
|---|---|
| MOSFETs | 100 V |
| Bulk + ceramic caps | 100 V |
| **SMCJ51CA TVS standoff (VRWM)** | **51.0 V** |
| TVS breakdown (VBR) | 56.7 V min, 62.7 V max |
| TVS clamping (VC @ 18.2 A) | 82.4 V |
| Measured peak Vds, switching | 55–59 V |

The 100 V silicon suggests a 60 V-capable drive. It is not. **The TVS standoff caps working bus voltage at 51 V**, and a fully charged 12S LiPo sits at 4.2 × 12 = **50.4 V — that is 1.2 % of margin.** Above 51 V the TVS enters its knee and leakage climbs; above 56.7 V it conducts hard.

So:

- **Max continuous bus: 51 V. Recommended: ≤ 48 V.**
- This is a 12S drive with no headroom at full charge, not a "56 V" drive.
- If anyone ever wants 13S or 14S, the TVS is the first thing that has to change — not the FETs.

Switching overshoot is a non-issue by comparison: 55–59 V peak against 100 V silicon is 45 % margin, confirmed across every drive setting simulated.

## Current

| Limit | Value | Set by |
|---|---|---|
| Measurement ceiling | ±27.5 A (CSA gain 20) / ±55 A (gain 10) | CSA range, 3 mΩ shunt, 3.3 V ref |
| Hardware OCP trip | ~83 A | Far above working range — firmware is the real protection |
| Shunt thermal | 0.71 W measured at 19.6 A rms vs 3 W rating | Ample |
| MOSFET pulsed | 179 A | Not limiting |
| **Continuous** | **thermal — see below** | The actual constraint |

## Thermal — the real rating, and the number nobody has yet

Simulated inverter dissipation (3 legs, 25 kHz, IDRIVE 0.57/1.14, no snubber):

| I_rms per phase | Inverter loss | + shunts |
|---|---|---|
| 10.6 A | 2.0 W | 2.9 W |
| 15.0 A | 3.6 W | 5.0 W |
| 19.6 A | 5.7 W | 7.8 W |

These are *cold-board* numbers; RDS(on) roughly doubles by 125 °C, so conduction loss (a minority of the total here) rises accordingly.

Converting this to a current rating needs **RθJA, which has not been measured.** Your bring-up plan already includes extracting it via RDS(on)-as-thermometer per JESD51-1 — that is the missing number, and until you have it any continuous current spec is a guess.

My estimate, for a compact multilayer board with no heatsink in still air (θ ≈ 15–25 °C/W board-to-ambient): **~10–12 A rms continuous.** With forced air or a heatsink, 20 A+ is plausible. Treat these as hypotheses to be tested, not specifications.

## Torque and speed, with the M8325s

Kt = 0.0827 Nm/A:

| Operating point | Phase current | Torque |
|---|---|---|
| Continuous (thermal est.) | ~10–12 A rms → 14–17 A pk | **1.2–1.4 Nm** |
| CSA ceiling, gain 20 | 27.5 A pk | 2.3 Nm |
| Motor continuous (free air) | 40 A | 3.3 Nm |
| Motor peak | 80 A | 6.6 Nm |

**The drive, not the motor, is the limiting element** — it accesses roughly a third of the motor's continuous torque. That is a legitimate design point for a legged robot (which lives at low duty), but it should be a conscious one.

Speed: 5040 RPM no-load at 50.4 V; ~3750 RPM with good current control at 25 kHz.

## Regenerative braking — the significant gap

There is no brake chopper and no regen clamp. Bus energy headroom before the TVS conducts hard:

```
E = ½C(V_BR² − V_bus²) = ½ × 300 µF × (56.7² − 50.4²) ≈ 0.10 J
```

To the 51 V standoff it is **9 mJ**.

With a healthy battery connected this is mostly fine — regen flows back into the pack through ~20 mΩ, and 10 A of regen lifts the bus only 0.2 V. The exposure is single-fault:

- **A BMS disconnect during deceleration** leaves regen energy with nowhere to go. Rotor kinetic energy for an 840 g pancake at speed is on the order of joules — one to two orders of magnitude above the 0.1 J the bus can absorb. The TVS is a 1500 W transient part, not a brake resistor.
- A full pack at 50.4 V has essentially zero regen headroom before the TVS starts leaking.

For a legged robot, which does substantial negative work every step, this deserves a decision rather than an omission: firmware regen current limiting, a brake chopper on the PDB, or an explicit "never run on a full pack" constraint. ODrive sells a separate regen clamp for exactly this reason.

## Control

| Parameter | Value |
|---|---|
| Current loop rate | f_sw (25 kHz recommended) |
| Current loop bandwidth | ~1.5–2.5 kHz typical |
| Position feedback | AS5047P, 14-bit on-board, ABI + SPI |
| Comms | CAN FD |
| Sensing | 3-shunt low-side, 3 mΩ, CSA gain 5/10/20/40 SPI-selectable |

Adequate for impedance control on a leg.

## Known open items carried forward

- **Shoot-through margin 0.06 V at as-built IDRIVE** (previous review). Unchanged by frequency — it is a per-edge phenomenon. Raise IDRIVE to 0.57/1.14 A; verify DRV8323 adaptive TDRIVE is enabled. 25 kHz makes a longer dead time cheaper if you need one.
- Snubbers stay DNP.
- Phase inductance unmeasured — gates the frequency decision.
- RθJA unmeasured — gates the current rating.
- VDDA/VREF on the raw digital 3V3 rail; DRV_CS pull-up missing; chassis bond resistors creating ground loops; E-stop lacking RC + ESD. All Rev 2.

## Summary spec, as I would write it today

```
Bus voltage         12S LiPo, 36–50.4 V     (hard ceiling 51 V, TVS-limited)
Continuous current  ~10–12 A rms/phase      (thermal, UNVERIFIED — needs RθJA)
Peak current        27.5 A                  (CSA gain 20; 55 A at gain 10)
Continuous torque   1.2–1.4 Nm              (with M8325s, Kt = 0.0827)
Max useful speed    ~3750 RPM @ 25 kHz
Switching           25 kHz recommended      (40 kHz only if ripple demands it)
Regen               none — battery sink only, ~0.1 J transient headroom
Feedback            AS5047P 14-bit absolute, on-board
Comms               CAN FD
Protection          OCP ~83 A, TVS 51 V standoff, E-stop → TIM1_BKIN2
```

The two numbers most worth measuring before anyone commits to this sheet are **phase inductance** and **RθJA**. Everything soft in the spec above traces back to one of them.

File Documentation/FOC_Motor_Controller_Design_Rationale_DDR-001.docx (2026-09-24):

FOC MOTOR CONTROLLER

Design Rationale and Decision Record

60 V / 10 A RMS per phase three-phase inverter

Quasi-direct-drive joint actuator for a cat-scale bipedal robot leg

STM32G431RBT6 · DRV8323S · Infineon OptiMOS 6 · CAN-FD

Document DDR-001 · Revision 1 · Status: PRELIMINARY

Compiled 20 August 2026

Prepared for open-source release

# Document Control

Field | Value
Document ID | DDR-001 — Design Rationale and Decision Record
Revision | 1 (initial consolidation)
Board revision covered | Rev 1 schematic set (18 exported sheets; internal numbering 1–19 with sheet 9 absent from the export)
Supersedes | None. Complements DRS-001 (Design Requirements Specification) and DFD-001 (Design Freeze, Rev C).
Design status | Schematic complete and reviewed; layout not started. Not built, not bench-validated.
EDA tool | KiCad (macOS). Altium Designer is used on Windows for unrelated work; this project is KiCad-native.
Sourcing references | DigiKey.ca and JLCPCB / LCSC parts library
Intended fabrication | JLCPCB, PCBA service

## Purpose

This document is the engineering record for the design decisions taken on this board. It is not a datasheet, not a build guide, and not a requirements specification — those are separate documents. Its purpose is to answer the question a reader of the open-source repository will actually ask: why is it like this?

Every entry records what was decided, what else was on the table, the reasoning that selected between them, and the cost that was knowingly accepted. Where a decision was later reversed or corrected, the reversal is recorded rather than quietly overwritten — a design record that only shows the winning branch teaches nothing.

## How to read this document

Sections 4 through 12 are organised as decision records. Each carries an identifier of the form D-xx and the following fields:

- Decision — what was chosen.
- Alternatives considered — what was rejected, named specifically.
- Rationale — the calculation, datasheet limit, or design principle that decided it.
- Trade-off accepted — what the decision costs. Every entry has one. Where this field says nothing was given up, the decision was probably not a real decision.
- Status — CONFIRMED (implemented in the Rev 1 schematic), PROPOSED (recommended, not yet implemented), SUPERSEDED (reversed by a later decision), or OPEN (still undecided and gating).

Section 13 collects the corrections to the design record — cases where an earlier conclusion in this project was wrong and was later fixed. Section 14 lists what is still open at the time of writing. Section 15 lists the literature the design was checked against; readers are encouraged to verify the reasoning against those sources rather than trusting this document.

## Honesty statement

Nothing in this document has been validated on hardware. All numbers are analytical (first-principles or datasheet-derived), and a subset have been checked in LTspice. Where a figure is an estimate rather than a datasheet value — most notably MLCC effective capacitance under DC bias — it is flagged as such at the point of use. The design has known open blockers, listed in Section 14, and a reader should not treat the schematic as release-ready.

# 1. System Context

## 1.1 What this board is for

The board is a single-axis field-oriented-control (FOC) motor controller intended to serve as the electronics for one joint of a legged robot. The target platform is a cat-scale bipedal leg using a quasi-direct-drive architecture — a low-gear-ratio, backdrivable transmission driven by a large-diameter, high-pole-count pancake outrunner. Six such boards are expected on a shared DC bus, one per joint, coordinated over CAN-FD.

This application choice drives almost everything downstream. Quasi-direct drive means torque control fidelity matters more than peak power, which makes current-sense accuracy a first-class requirement rather than an afterthought. Legged locomotion means impact loading and frequent regeneration, which makes bus transient behaviour a safety problem rather than an efficiency problem. Six boards on one bus means every fault mode has to be considered in aggregate, not per board. And a leg means mass is a real constraint, which is why an over-specified power stage is treated as a defect in this document rather than as free margin.

## 1.2 Reference motor and electrical envelope

Parameter | Value | Note
Reference motor | ODrive M8325s, 100 KV | 92 mm pancake outrunner, 20 pole pairs
Battery | 12S LiPo | 50.4 V full charge, ~44.4 V nominal, 36 V undervoltage cutoff
Bus, stated max | 56 V | Cover-sheet figure; 60 V treated as absolute ceiling
Phase current, design point | 10 A RMS continuous | Thermally validated analytically; not a rated figure
Phase current, stress point | 20 A | Analysed, thermally acceptable; 30 A requires chassis heatsinking
Switching frequency | 40 kHz target | Not yet frozen in firmware — see D-09 and Section 14
Electrical frequency at 3500 rpm | ~1167 Hz | 20 pole pairs; drives the minimum f_PWM argument
Control architecture | Sensored FOC, absolute magnetic encoder | Sensorless observer considered and rejected — see D-20

The 20 pole pairs are the reason 40 kHz was chosen rather than a more conventional 20 kHz. Electrical frequency is mechanical speed multiplied by pole pairs; at 3500 rpm that is roughly 1167 Hz. Applying the conventional rule of at least 20 PWM cycles per electrical cycle gives a floor of about 25 kHz. 40 kHz provides headroom above that floor, keeps operation ultrasonic, and reduces current ripple — at the cost of a tighter gate-charge budget, which became the governing constraint on MOSFET selection (see D-06).

## 1.3 Functional architecture

The signal chain, in order:

XT60 → hot-swap / input protection (LM5069) → +VPROT bus

├─ bulk capacitance → three-phase inverter (6 × OptiMOS 6) → motor

│ └─ low-side shunts → DRV8323S CSAs → STM32G431 ADC1/ADC2

├─ DRV8323S gate driver (SPI-configured, integrated charge pump)

└─ step-down → +5 V → +3V3 (digital) and +3V3A (analog LDO)

Position: off-board magnetic encoder → SPI over JST-GH

Comms: CAN-FD (TCAN transceiver) + USB-C via CH340X UART bridge

Debug: SWD, status LEDs, board and motor NTC channels

# 2. Design Process

The project followed a fixed workflow, applied to each subsystem in turn. It is recorded here because the sequence itself was a deliberate methodological choice and shaped which decisions were made when.

Stage | What happens | Deliberate constraint
1. First-principles | Derive the governing physics and the napkin numbers for the subsystem. | No optimisation at this stage. The goal is order of magnitude and identification of the binding constraint, not a final value.
2. SPICE | Build a model from the napkin result and optimise there. | Simulation is used for device- and power-stage behaviour only, never for the FOC control loop — see the note below.
3. Component search | Select real parts against the simulated specification. | Availability checked against DigiKey.ca and JLCPCB before a part is written into the schematic.
4. Power and thermal | Loss and junction-temperature calculation at design and stress operating points. | Hot R_DS(on), not the 25 °C headline figure.
5. BoM consolidation | Rationalise line items across the whole board. | Done once the design is stable, not during design — early consolidation biases component choices for the wrong reason.
6. Schematic review | Full-sheet review against datasheets and prior decisions. | Checks that action items from earlier stages actually landed.
7. Layout reference | Placement, stackup, grounding, and thermal strategy. | Not started at the time of writing.

## 2.1 Why LTspice is not used for the control loop

An early attempt to simulate the FOC loop was abandoned after establishing that the timescale separation between device switching (nanoseconds) and mechanical response (hundreds of milliseconds) spans seven to eight orders of magnitude. A SPICE transient solver forced to resolve nanosecond switching edges across a mechanical settling time is not merely slow, it accumulates numerical error that swamps the result. Control-loop behaviour belongs in a discrete-time simulation environment; SPICE is used here strictly for the power stage.

Three benches were built and are part of the project record:

- dpt_halfbridge.cir — double-pulse test on one half-bridge, used to relate commutation loop inductance to V_DS overshoot and gate ringing.
- input_stage_transients.cir — input protection behaviour under hot-plug and inductive transient.
- bus_regen_cascade.cir — multi-board shared-bus regeneration, used for the brake-chopper decision.

The single most consequential simulation result in the project came from dpt_halfbridge.cir: negative gate ringing grows from roughly 0 V at 2 nH of commutation loop inductance to about −4.9 V at 80 nH. Gate-oxide stress and the risk of false turn-off therefore appear well before drain overshoot becomes visually alarming. This is why loop area is treated in Section 11 as the number one layout variable rather than as one of several.

# 3. Design Evolution

The board did not arrive at its present form in one step. The major transitions are recorded here because several of them were triggered by a specific error being caught, and those are the most instructive parts of the record.

Phase | Configuration | What ended it
Rev A | STM32F405, CSD18540Q5B MOSFETs (40 V), initial architecture | The 40 V MOSFET rating on a 60 V bus was identified as a guaranteed failure, not a marginal one. Forced a full power-stage re-specification.
Rev B | STM32G431CBU6, DRV8323S, IPT015N10N5 (100 V, 1.5 mΩ) | Loss analysis showed the ultra-low-R_DS(on) part had the worst total loss of the candidates at 40 kHz because switching loss dominates at this current. Selection metric changed from R_DS(on) to figure of merit.
Rev C | OptiMOS 6 family selected; formal design freeze document produced | Freeze exposed two contradictory instructions carried forward from earlier work (shunt value, Qg ceiling). Both were re-derived and corrected — see Section 13.
Rev 1 | STM32G431RBT6 (LQFP64), DRV8323SRTAR, ISC030N10NM6, LM5069 hot-swap front end, off-board encoder, CAN node-ID ladder, drain-side snubber removed | Current state. Schematic reviewed; three blockers open (Section 14).

## 3.1 The three errors worth reading about

The 40 V MOSFET. The Rev A power stage used a part rated at 40 V V_DS on a bus whose full-charge voltage is 50.4 V. This is not a margin question; the device is outside its absolute maximum rating at rest. It survived into a schematic because component selection had been anchored on R_DS(on) and package without a voltage-margin gate. The rule adopted afterwards — voltage rating checked first, against worst-case bus transient rather than nominal bus — is now the first line of D-05.

The loss inversion. Having corrected the voltage rating, the natural next move was to reach for the lowest R_DS(on) 100 V part available, which is how IPT015N10N5 (1.5 mΩ) entered the design. Running the loss numbers at the actual operating point showed the opposite of the intuition:

At 40 A RMS, 40 kHz, 50 V bus, I_DRIVE = 1 A:

R_DS(on) 2.24 mΩ : P_cond 2.69 W + P_sw 1.58 W = 4.27 W

R_DS(on) 2.70 mΩ : P_cond 3.24 W + P_sw 1.36 W = 4.60 W

R_DS(on) 1.50 mΩ : P_cond 1.80 W + P_sw 3.85 W = 5.65 W ← lowest Rds(on), worst total

The 1.5 mΩ part loses because its gate-to-drain charge is two to three times higher, and at this current and frequency switching loss dominates conduction loss. The selection metric was changed to figure of merit (R_DS(on) × Qg, lower better), which is the metric that survived into the final choice.

The ordering code. Guidance carried through several revisions specified DRV8323SRTVR. Checking the nomenclature table in the device datasheet showed RTV to be the 32-pin 5×5 package used only on the DRV8320; the 40-pin 6×6 WQFN part actually required is DRV8323SRTAR. The schematic symbol was correct throughout — the written note was wrong. This is recorded because it is the class of error that survives review indefinitely if the note and the symbol are never checked against each other.

# 4. Input Protection and Power Front End

### D-01 — Hot-swap controller rather than a passive input stage

Decision: Use a TI LM5069 hot-swap controller with back-to-back pass FETs as the input stage, providing inrush limiting, undervoltage lockout, overvoltage lockout, current limiting, and reverse-polarity protection in one block.

Alternatives considered: Passive input stage: fuse, TVS, and an ideal-diode P-channel reverse-polarity FET. Simpler and lighter, but provides no inrush control and no fault current limit.

NTC inrush limiter with a bypass relay. Adds mass and a mechanical part per joint.

Slew-controlled reverse-polarity FET doing double duty as a soft-start element. Considered seriously; rejected because it gives inrush control without fault current limiting.

Rationale: Connector mating on a 12S pack into 500 µF of bulk capacitance is an energetic event. The stored-energy figure at full charge is roughly 0.66 J into the pass devices, which is a safe-operating-area problem, not a current-rating problem.

The board is one of six on a shared bus. A short on one joint must not collapse the bus for the other five. A current-limited, latching front end localises the fault.

Trade-off accepted: Cost, board area, and one more failure mode in the power path. The pass FETs must be selected for SOA rather than R_DS(on) — a linear-mode-rated device — which is a narrower and more expensive part class than an ordinary switching FET.

Status: CONFIRMED. Q1/Q2 (back-to-back pass FETs) still have no manufacturer part number assigned in the Rev 1 schematic — this is a hard gap, listed in Section 14.

### D-02 — LM5069-1 (latch-off) rather than LM5069-2 (auto-retry)

Decision: Use the latch-off variant. On a fault, the joint stays off until the bus is power-cycled.

Alternatives considered: The -2 auto-retry variant, which re-attempts after a timeout.

Rationale: Auto-retry into a genuine short is a repeated high-energy event on the pass FETs. Latching converts an ambiguous, repeating fault into a single unambiguous one.

Trade-off accepted: A tripped joint on a robot in the field is dead until someone power-cycles it, and firmware must never be able to clear the latch — a joint that can retry into a short by itself is worse than a dead joint. The reset path is therefore hardware: the UVLO pin is brought out to a test point and a momentary reset. This is also the argument that pushes toward a system-level contactor (D-19), since without one there is no remote way to recover a latched joint.

Status: CONFIRMED, with a live counter-argument. For a legged robot the auto-retry variant is defensible and was flagged for reconsideration during the Rev 1 review. Recorded here as a decision a fork may reasonably reverse.

### D-03 — TVS selection — an unresolved conflict, documented rather than hidden

Decision: SMCJ51CA bidirectional TVS on the input. This is known to be an incomplete solution.

Alternatives considered: SMBJ58CA — analysed and rejected: its clamping voltage at rated peak pulse current is 93.6 V, which is 44 % above the DRV8323's 65 V absolute maximum V_M rating.

Two-stage TVS with series impedance — investigated and set aside for board area.

Series ferrite or small resistance plus a local low-voltage clamp at the DRV8323 V_M pin.

Accept the 60 V-class gate driver as the limiting component and control transients purely by layout.

Rationale: The constraint is arithmetic and has no clean solution. On a 12S pack the TVS standoff voltage must exceed 50.4 V, so 51 V is about the lowest usable standoff. No standard TVS with a 51 V standoff clamps below roughly 62 V at rated surge current — the required clamping ratio does not exist in the standard product range.

SMCJ51CA clamps at approximately 82 V. The MOSFETs (100 V) and the buck (80 V absolute maximum V_IN) survive that; the DRV8323 (65 V absolute maximum) does not.

Trade-off accepted: As drawn, the part whose job is to protect the board clamps above the survival limit of one of the two most expensive ICs on it. The board is protected against destructive surge but the gate driver is the sacrificial element.

Status: OPEN — BLOCKER. This is the single most important unresolved item in the design and is recorded as such rather than papered over. It must be decided explicitly, not by default.

### D-04 — Gate driver voltage class — DRV8323 (60 V) with 100 V everything else

Decision: Retain the DRV8323S, a 60 V-family device, alongside 100 V MOSFETs and 100 V bulk capacitors.

Alternatives considered: DRV8353S, the 100 V-class sibling. Not pin-compatible.

Rationale: The DRV8323 provides the required feature set: three-phase gate drive, SPI configuration of I_DRIVE and dead time, integrated charge pump, three current-sense amplifiers, and V_DS-based overcurrent protection.

The topology is proven at this voltage — ODrive v3.6 pairs a 60 V-class driver (DRV8301) with a comparable bus.

Trade-off accepted: Every other component in the power path carries roughly 2× voltage margin; the gate driver carries about 1.2×. The gate driver, not the MOSFETs, is the true ceiling of the design. This makes transient control mandatory rather than good practice, and it is what makes D-03 a blocker instead of a refinement.

Status: CONFIRMED, but this is a decision with an expiry date. The DRV8353S is not pin-compatible, so the swap must happen before layout or not at all.

### D-05 — Generator-mode hazard — acknowledged, not yet mitigated

Decision: No dedicated mitigation for the back-drive-into-open-switch condition in Rev 1.

Alternatives considered: A clamp on the protected bus node; the auto-retry hot-swap variant; a brake chopper.

Rationale: The DRV8323 datasheet describes this case directly: with a switch between the battery and V_M/V_DRAIN — which is exactly what the hot-swap FETs are — a back-driven motor drives the switch node above a collapsing V_M and current flows through internal diodes into V_M. On a leg absorbing an impact, this is a realistic event rather than a theoretical one.

Trade-off accepted: With the pass FETs off, regeneration energy has nowhere to go except 500 µF of bulk capacitance and whatever the internal diodes will pass. The SPICE bus-regen bench produced a 154 V excursion on an unclamped disconnect during regeneration on a 60 V-rated board, which quantifies the exposure.

Status: OPEN — BLOCKER. Interacts directly with D-02 and D-19.

# 5. Inverter Stage

### D-06 — MOSFET selection by figure of merit, not R_DS(on)

Decision: Infineon ISC030N10NM6 (OptiMOS 6, 100 V, 3.0 mΩ max at V_GS = 10 V, Qg 55 nC, Qgd 14 nC max, TOLL package).

Alternatives considered: IPT015N10N5 (100 V, 1.5 mΩ) — the incumbent. Rejected: highest total loss of the candidate set at 40 kHz, and 169 nC typical / 211 nC maximum Qg sits at the charge-pump limit.

ISC022N10NM6 and ISC027N10NM6 (SuperSO8) — strong candidates by FOM, initially recommended.

JLCPCB's 100 V TOLL inventory: GT016N10TL (165 nC), NCEP023N10LL (240 nC), NCEP020N10LL (252 nC). All rejected on gate charge.

Rationale: Selection is constrained by the gate driver's charge pump, not by conduction loss. Required charge pump current is approximately three times the high-side gate charge times switching frequency; at 55 nC and 40 kHz across six devices this is 13.2 mA against a 25 mA budget, a 1.9× margin.

The entire JLCPCB 100 V TOLL stock is optimised for 200–360 A battery and BMS applications. Those parts buy R_DS(on) the design does not need by paying gate charge the design cannot afford. This is a case where local sourcing convenience had to lose to the electrical requirement.

Trade-off accepted: The part is not stocked by the assembly house, so it becomes a consigned or extended-library line. This is a real cost in a JLCPCB-assembled design.

More significantly: the TOLL package is thermally over-specified for 10 A. Six TOLL packages occupy roughly 700 mm² of board area for a stage whose total conduction loss at the design point is under one watt. On a robot leg, where board mass is a live constraint, this is over-provisioning, not free margin. A 5×6 mm PQFN at around 5 mΩ would deliver the same junction temperature at a fraction of the area and mass. This was flagged before layout precisely because it sets board size.

Status: CONFIRMED as the part; the package choice is flagged for reconsideration before layout.

### D-06 supporting analysis — loss and thermal

Conduction loss uses a hot R_DS(on) of approximately 6 mΩ — roughly double the 25 °C figure, taken from the datasheet's temperature-coefficient curve — rather than the 3.0 mΩ headline value. Switching loss uses the datasheet rise and fall times of 4.5 ns and 5.3 ns, measured at conditions close to the operating point.

Phase current | P_cond (3 legs) | P_sw (6 FETs) | P per FET | T_j at 40 °C ambient
10 A (design point) | 1.80 W | 0.71 W | 0.42 W | 61 °C
20 A (stress) | 7.20 W | 1.41 W | 1.44 W | 112 °C
30 A | 16.2 W | 2.1 W | ~3.0 W | Requires chassis heatsinking

Thermal resistance junction-to-ambient of 50 °C/W is the datasheet figure for a modest 6 cm² single-layer copper pad with no heatsinking — deliberately the worst case. Against a 175 °C junction limit, the design point has very large margin and 20 A continuous remains comfortable. The conclusion that matters for the rest of the design: at 10 A the inverter is thermally uncritical, which is what makes the package over-provisioning trade-off in D-06 a real one.

### D-07 — No drain-source RC snubber; dv/dt controlled at the gate instead

Decision: Delete the per-leg drain-to-source RC snubber. Control slew rate with the DRV8323's programmable I_DRIVE plus a gate-source RC network (3.9 Ω + 2.2 nF per FET), with 0 Ω series gate resistors populated so that I_DRIVE has sole control and the footprints remain available for tuning.

Alternatives considered: Drain-source RC snubber per half-bridge, sized for critical damping of the loop-inductance / C_OSS resonance. This was the earlier baseline and carried an open action item on resistor power rating.

Switch-node-to-ground snubber.

Asymmetric gate network — series resistor with a parallel diode — to slow turn-on while keeping turn-off fast.

Rationale: The asymmetric R-plus-diode network is a workaround for gate drivers that offer only a single fixed drive current. The DRV8323's Smart Gate Drive already provides independently programmable source and sink currents over SPI — the same asymmetry, implemented internally. TI's own application note recommends a single small or 0 Ω series resistor as the external gate network when Smart Gate Drive is in use.

Deleting the diode network removes parasitic capacitance from the gate loop and removes a real line item, which is a larger BoM saving than any part-number substitution.

A gate-side approach also makes slew rate tunable in firmware after the board exists, rather than requiring a resistor change.

Trade-off accepted: Damping now depends on a driver setting rather than on passive components. If the commutation loop turns out worse than modelled, the recovery path is slower switching — which costs efficiency — rather than a component change.

A previously flagged concern about the 1N4148's 500 mA repetitive current rating against roughly 1.6 A of peak gate current became moot once the FET changed and I_DRIVE settled around 280 mA. The premise disappeared with the part, which is why the diode decision was re-opened rather than inherited.

Status: CONFIRMED in the schematic but NOT VALIDATED. This replaced a sized snubber with a removed snubber, which raises rather than lowers the priority of the LTspice half-bridge work. Recommendation on record: add unpopulated drain-source snubber footprints as insurance before layout.

### D-08 — Bulk capacitance sized by ripple-current capacity, not capacitance

Decision: Five 100 µF / 100 V aluminium-polymer capacitors (500 µF nameplate, roughly 7 mΩ combined ESR) plus MLCCs at each half-bridge input, targeting approximately 2 % bus ripple.

Alternatives considered: All-MLCC — rejected: DC-bias derating and limited energy storage.

MLCC plus aluminium electrolytic — rejected on ESR and lifetime.

Three polymer capacitors — rejected: 7.5 A ripple capacity against a 7.8 A requirement.

Four — rejected: 104 % of requirement, borderline on a 2000-hour part.

TDK B40910A0107M100, an SMD part with better ESR — rejected on a 19-week lead time.

A 63 V SMD alternative — rejected: about 5 % headroom on a 60 V absolute-maximum bus.

Rationale: Capacitance was never the binding constraint — three pieces already provide roughly 322 µF effective. Piece count is set by can surface area and thermal ripple-current capacity. Five pieces give 12.5 A against 7.8 A required. The MLCC bank contributes only about 7–10 % of ripple current after DC-bias derating; its role is ESL reduction at the half-bridge inputs, not bulk ripple absorption, and it must not be counted toward reducing the polymer count.

Trade-off accepted: Five through-hole cans is mass and height on a board where both matter, and Z-height must be checked against enclosure clearance before layout.

100 V rating was retained to preserve a 75 % derating ratio rather than accepting the thinner margin of a 63 V part.

Status: CONFIRMED. One unverified input: MLCC effective capacitance of approximately 22.6 µF at 50 V bias is an estimate, not a value pulled from the manufacturer's DC-bias curve. The conclusion is robust to a large error in that estimate — the polymer bank carries over 90 % of ripple regardless — but the number itself should be verified before release.

### D-09 — 40 kHz switching frequency

Decision: Target 40 kHz.

Alternatives considered: 15–20 kHz (easier charge-pump budget, lower switching loss, simpler EMI filtering, but audible and coarser current ripple) or 30 kHz.

Rationale: Set by the motor's 20 pole pairs. At 3500 rpm the electrical frequency is about 1167 Hz; at 20 PWM cycles per electrical cycle the floor is roughly 25 kHz. 40 kHz gives headroom, stays ultrasonic, and smooths the current waveform.

Trade-off accepted: Higher switching loss, a tighter charge-pump budget that became the governing MOSFET constraint, and more demanding EMI filtering. This single number cascades into gate charge, snubber sizing, filter cutoff, and audible noise — it is the most load-bearing number in the design.

Status: OPEN. The value is a target, not frozen in firmware or recorded on the schematic. Both the snubber work and the bulk-capacitance sizing depend on it, so it should be fixed first.

# 6. Current, Voltage and Temperature Sensing

### D-10 — Low-side shunts with the gate driver's integrated amplifiers

Decision: Three low-side shunt resistors, one per phase, feeding the DRV8323's integrated current-sense amplifiers. Kelvin sensing via net ties. Dual-simultaneous ADC sampling triggered from the centre-aligned PWM event.

Alternatives considered: In-line phase current sensing with isolated or high-side amplifiers — better duty-cycle coverage, materially more cost and complexity. Two-shunt sensing with the third phase reconstructed — saves a channel but loses redundancy.

Rationale: Centre-aligned sampling at the PWM event is not optional for Clarke/Park accuracy; switching transients must have settled before the sample is taken, and filtering alone cannot substitute for correct sample timing. Kelvin sensing keeps power-loop current out of the sense path.

Trade-off accepted: Low-side sensing loses visibility at very high duty cycle. Accepted for this application because the torque-control operating region does not sit at the duty-cycle extremes.

Status: CONFIRMED.

### D-11 — Shunt value — 3 mΩ, arrived at after a corrected reversal

Decision: 3 mΩ, 3 W, 2512 package, with CSA gain of 20 V/V. Full scale is approximately ±27.5 A about the mid-reference.

Alternatives considered: 5 mΩ with gain 10 V/V — the frozen Rev C value, giving ±33 A full scale and 0.50 W dissipation at 10 A RMS.

5 mΩ with gain 20 V/V — only 1.17× headroom over the 14.1 A peak; too tight for transients.

2 mΩ with gain 20 V/V — the correct pairing if the design point rises above roughly 20 A RMS.

1 mΩ — see Section 13; this instruction was inherited from a different operating point and retracted.

Gain 40 V/V — rejected outright: reaches only ±13.75 A full scale, below the peak current.

Rationale: Shunt value and amplifier gain are one decision, not two. Sizing is driven by keeping the amplifier input within range at peak current while retaining enough full-scale headroom for transients, subject to the resistor's power rating. At 3 mΩ the dissipation is 0.3 W each at 10 A RMS and 1.2 W at 20 A peak, within a 3 W part.

Trade-off accepted: Lower shunt resistance trades sense resolution for thermal headroom the design does not currently need. A consequence not immediately obvious: at 3 mΩ the gate driver's dedicated shunt-based overcurrent input is unusable, because its threshold works out to a trip current in the hundreds of amps. Overcurrent protection therefore rests entirely on V_DS-based detection.

Status: CONFIRMED, with the V_DS trip level still to be set. The V_DS threshold must be computed as trip current multiplied by hot R_DS(on), and the latch-versus-retry mode chosen.

### D-12 — Bus voltage divider — split upper leg, and a bandwidth limitation accepted

Decision: Three-resistor divider (24.9 kΩ + 12.4 kΩ upper legs, 2 kΩ lower leg) into an ADC channel, with a zener clamp to the analog rail as a backstop and a 100 nF filter capacitor.

Alternatives considered: A single-resistor upper leg, and the earlier 39 kΩ / 2.2 kΩ two-resistor divider.

Rationale: The upper leg is split across two bodies so that no single 0402 resistor sees the full bus voltage — at 56 V a single element would exceed the usual 50 V per-part working-voltage limit. This is a working-voltage decision, not a tolerance decision.

A supporting BoM finding: both values were already on the board, so splitting the leg cost nothing in line items and removed a latent working-voltage violation at the same time.

Trade-off accepted: Thevenin source impedance of roughly 1.9 kΩ with 100 nF gives a time constant near 190 µs and a corner near 840 Hz. That is adequate for bus monitoring and regeneration fold-back but explicitly too slow to serve as a fast overvoltage trip — the fault bus-rise window is on the order of 280–580 µs, and a 190–208 µs filter lag consumes most of it. The zener is the only fast clamp on that node.

The divider draws roughly 1.4 mA continuously from the pack and is not switched.

Status: CONFIRMED with a known limitation. A prior analysis concluded the filter capacitor should be reduced to 1 nF (corner ~76 kHz) specifically so this node could serve as a fast trip; the Rev 1 schematic retains 100 nF. If a fast trip is wanted, this is a one-component change and is listed in Section 14.

### D-13 — Two NTC channels: board and motor

Decision: An on-board 10 k NTC in a 10 k/10 k divider for board temperature, and a separate motor NTC channel.

Alternatives considered: Board sensing only; a motor NTC divider using a 2 kΩ leg.

Rationale: The on-board NTC measures board temperature, not junction temperature — a distinction worth stating explicitly on the schematic so that firmware does not treat it as a junction estimate. Motor windings are the component most likely to overheat first in a quasi-direct-drive joint, and they are not observable from the board.

Trade-off accepted: A 2 kΩ lower leg concentrates ADC resolution near the overheat trip point at the cost of throwing away the cold end of the range. A 10 kΩ leg gives a symmetric pair and full-range resolution. The choice is a genuine fork: overheat detection versus temperature tracking. It depends on whether firmware needs to model winding temperature or merely trip on it.

Status: OPEN. The specific NTC part and its beta constant are not yet fixed, and the R-T table and firmware lookup cannot be generated until they are. Note that a motor NTC generally needs a higher maximum temperature rating (150–180 °C class) than a board sensor.

### D-14 — Analog rail from a dedicated LDO, distributed as traces not a pour

Decision: Separate analog 3.3 V rail from its own LDO, fed from the 5 V rail, distributed in a star topology using individual traces with local decoupling at each leaf.

Alternatives considered: A copper zone covering the analog region — the original layout proposal; sharing the digital 3.3 V rail.

Rationale: The total analog load is tens of milliamps at worst. Ten milliamps through a 0.3 mm trace on 1 oz copper over 60 mm produces roughly 90 µV of IR drop against an 806 µV LSB — about a tenth of an LSB. The low-impedance argument that justifies a power pour simply does not apply at this current.

A pour, by contrast, actively hurts. It behaves as a slot in whatever plane it displaces, diverting return currents on adjacent layers — the dominant noise mechanism on a board with 100 V devices switching nearby, far larger than any IR drop it saves. Its plate area also couples dv/dt capacitively; a trace has roughly a hundred times less. And with a pour you cannot enforce a star topology or see where current actually flows.

Trade-off accepted: More routing effort and more discipline required: every analog trace must run over unbroken ground for its whole length and must route around the switching region rather than through it.

Status: CONFIRMED as the routing strategy. Two supporting items remain open: whether the ADC reference is tied to the analog rail, driven by the internal reference buffer, or externally supplied — this determines whether LDO ripple becomes gain error on every channel — and whether an input filter is needed ahead of the LDO. A small LDO offers perhaps 40 dB of rejection at 100 kHz and only 10–20 dB by 1 MHz, so roughly 10 mV of ripple can reach the analog rail, which is about 12 LSB of reference wander — more error than the converter's own unadjusted error budget.

### D-15 — ADC channel pairing — a firmware constraint created by pin assignment

Decision: Accept the pin assignment as routed and document the resulting constraint.

Rationale: Of the three current-sense channels, one lands on a pin available to both ADC instances while the other two are on ADC1-only pins. Dual-simultaneous sampling must therefore always pair the shared channel on ADC2 with one of the other two on ADC1. Phases B and C can never be sampled together.

Trade-off accepted: Workable — the third phase current is reconstructed from Kirchhoff's current law — but it is a permanent firmware constraint created by a layout-convenience pin assignment, and it must be documented now rather than discovered during bring-up.

Status: CONFIRMED and documented.

# 7. Microcontroller and Gate Drive

### D-16 — STM32G431RBT6 in LQFP64

Decision: STM32G431RBT6, LQFP64.

Alternatives considered: STM32F405 (the Rev A choice); STM32G431CBU6 (the Rev B choice, a smaller package).

Rationale: The G4 family provides the advanced timer with complementary outputs, dead-time insertion and break inputs, plus dual ADCs capable of simultaneous injected conversion — the exact peripheral set FOC requires.

The move from the UFQFPN package to LQFP64 was driven by pin count. Peripheral demands — three current-sense channels, bus and two temperature channels, SPI to the encoder, SPI to the gate driver, CAN-FD, UART bridge, node-ID strap, status LEDs, enable and fault lines — exceeded what the smaller package could supply without conflicts. LQFP64 also assembles and reworks more easily on a hand-populated prototype.

Trade-off accepted: Larger footprint on a board where area is contested. An earlier feature — a Qwiic expansion connector — was dropped when pin constraints were tighter and was not reinstated.

Status: CONFIRMED.

### D-17 — UCPD dead-battery pull-downs — a silicon behaviour that becomes a firmware requirement

Decision: Accept the pin assignment and impose a hard firmware requirement instead of moving pins.

Rationale: On this device, two port-B pins carry internal 5.1 kΩ pull-downs associated with the USB-C controller, and those pull-downs are enabled by a high level on two specific port-A pins. In this design those port-A pins are two of the high-side PWM outputs. The consequence is that starting the timer enables pull-downs on a UART line and an LED line.

Trade-off accepted: The consequence is tolerable here — a pulled-down UART transmit line and a dimmed LED — but it converts a silicon detail into a mandatory firmware ordering requirement: the dead-battery disable bit must be set before the timer is enabled. This is exactly the class of issue that costs days at bring-up if it is not written on the schematic.

Status: CONFIRMED, with the requirement recorded as a design note on the MCU sheet. This issue was found, fixed by re-assignment, and then reappeared after a later pin shuffle — which is itself an argument for putting constraints on the schematic rather than in a changelog.

### D-18 — Quartz crystal rather than ceramic resonator for the high-speed oscillator

Decision: Replace the 8 MHz ceramic resonator with an 8 MHz quartz crystal plus two load capacitors.

Alternatives considered: Retain the ceramic resonator (smaller, roughly three to five times cheaper, integrated load capacitors, faster startup, two fewer components).

Rationale: The ceramic resonator's total tolerance is about ±0.5 % — roughly 500 times looser than a typical ±10 to ±20 ppm quartz part. That is marginal for classical CAN and generally insufficient for CAN-FD data-phase bit timing, where the error budget must accommodate both nodes.

There is no competing constraint: the MCU's USB peripheral is unused (USB-C goes only to the UART bridge), so the crystal serves the timer and CAN clock trees and nothing else.

Quartz also gives cleaner phase noise into any PLL driving high-resolution PWM timing.

Trade-off accepted: About 35 cents, a footprint change from three pins to two pins plus two capacitors, and slightly slower oscillator startup. Attempting to dodge this by slowing the CAN-FD data rate was considered and rejected — the tolerance is out of budget for classical CAN in many topologies regardless.

Status: PROPOSED. The Rev 1 schematic still carries the ceramic resonator. This is a cheap, well-understood fix and should land before layout.

### D-19 — Safety architecture — two mechanisms on two timescales

Decision: Separate the graceful stop from the safe stop. A hardware disable path takes the inverter to a safe state in microseconds; a controlled deceleration and system power removal happen on a longer timescale. Target the equivalent of a Stop Category 1: signal-level disable at t = 0, contactor opening at roughly 500 ms, timed in hardware rather than firmware.

Alternatives considered: Wiring the e-stop into the hot-swap controller's UVLO pin. This is the pin the manufacturer advertises for remote shutdown and is the wrong choice here: it removes bus power instantly, which drops the motor to coast in the worst possible way and kills the MCU before it can report anything.

A firmware-only disable over CAN. Rejected: a stuck signal line and a crashed controller are indistinguishable.

Signal-line disable only, with no contactor.

Rationale: Power-down ordering works in the design's favour and should be exploited rather than fought: the gate driver's undervoltage lockout is around 6 V while the step-down converter runs down to about 4.2 V input, so on bus collapse gate drive dies before logic does. That window is what lets the MCU log and report the fault.

Every open-source reference design surveyed — ODrive, moteus, OpenPodcar, ODRI — kept a physical stop mechanism independent of the compute path. None used a software stop as the sole safety mechanism. A level signal alone tells the board what the controller wants right now but has no opinion about whether the controller is still alive, which is the gap a heartbeat closes.

The 500 ms delay before contactor opening gives every node time to emit a CAN fault frame, and the contactor doubles as the remote reset for latched hot-swap controllers on the whole bus — which is what makes D-02's latch-off choice liveable.

Trade-off accepted: A contactor is mass, cost, and a new failure mode (welded contacts). Without one, a latched joint requires physical access and there is no backstop if the signal chain itself fails.

Status: PROPOSED and partially designed — power-good sequencing chain, an AND-gate enable, external pull-downs on the driver enable and calibration pins, and the hardware break path from the fault line into the timer. But the Rev 1 schematic has NO external e-stop input: the driver enable is MCU-only. A 12S leg that can kick deserves a disable line that does not depend on firmware or the CAN stack being alive. Listed in Section 14.

### D-20 — Sensored FOC with an absolute magnetic encoder

Decision: Absolute magnetic encoder over SPI as the primary position source.

Alternatives considered: Sensorless FOC using a state observer, or direct back-EMF sensing with phase voltage dividers.

Rationale: A quasi-direct-drive joint must produce controlled torque at and near zero speed, where back-EMF is by definition unavailable. Sensorless operation cannot hold position under load, which is the primary duty of a leg joint.

Trade-off accepted: A sensor, a connector, a cable, and a magnet-to-rotor mechanical interface, all of which can fail. Phase voltage sensing was retained as a secondary capability rather than a primary control input.

Status: CONFIRMED.

### D-21 — Encoder moved off-board — the most contested decision in the project

Decision: No position sensor on the board. The encoder SPI bus reaches connectors only; the sensor lives on a separate small board near the rotor, connected by a 7-position JST-GH cable.

Alternatives considered: On-board magnetic encoder with the magnet mounted on the rotor, requiring the controller board to sit coaxially with the motor shaft.

Rationale: Mechanical freedom. An on-board sensor forces the controller into a specific position and orientation relative to the motor. Off-board sensing lets the controller mount remotely on a structural member, which was the mounting strategy chosen for the leg.

Trade-off accepted: This is, on the review record, the most likely source of intermittent field failures in the design. It runs an unshielded SPI bus over a moving cable, inside a joint, alongside a 40 kHz inverter and the phase conductors — a close-to-worst-case environment for a synchronous serial bus with no error detection.

Mitigations available without redesign: cap the SPI clock at 2 MHz or below, retain series damping resistors, use twisted or shielded cable with the shield returned to chassis, and enable the sensor's frame parity or CRC in firmware.

The full fix — on-board sensor plus rotor magnet — costs roughly five dollars plus mechanical work, and forfeits the mounting freedom that motivated the decision in the first place.

Status: CONFIRMED but flagged. A reader forking this design for a mechanically simpler joint should seriously consider reversing it. The connector interface deliberately shares the on-board SPI bus so that either arrangement is supportable.

# 8. Communications, Connectors and Expansion

### D-22 — CAN-FD as the control bus

Decision: CAN-FD via a TI transceiver, with jumper-selectable split termination and a hardware node-ID selector.

Alternatives considered: Classical CAN; EtherCAT; RS-485.

Rationale: CAN-FD is the convergent choice across the comparable open-source designs surveyed (ODrive, moteus). It provides deterministic multi-drop on a six-node bus with enough payload for FOC command and telemetry frames, over a two-wire harness that suits a limb.

Trade-off accepted: Bit-timing tolerance is tight enough to force the crystal decision in D-18. Bus bandwidth is also a hard ceiling on how much telemetry can be streamed per joint.

Status: CONFIRMED, with the exact transceiver ordering code still to be verified — the variant in the project files differs from the one specified in the schematic, and pin 5 carries a different function between variants.

### D-23 — Termination — exactly two terminators on the bus, not one per board

Decision: Jumper-selectable split termination on each board, with exactly two enabled at the two physical ends of the six-node bus.

Rationale: Six boards each carrying a fixed 120 Ω terminator would load the bus to 20 Ω and prevent it working at all. Making termination selectable per board keeps every board identical while allowing correct bus topology.

Trade-off accepted: A configuration step at assembly, and a configuration mistake that is invisible until the bus misbehaves. The split termination also requires the common-mode choke to sit in the correct order relative to the split point.

Status: CONFIRMED.

### D-24 — Hardware node ID by resistor ladder into an ADC

Decision: A four-position jumper or DIP arrangement driving a binary-weighted resistor ladder into a single ADC channel, giving 16 addresses from one pin. Read once at boot before the inverter is enabled.

Alternatives considered: Four dedicated GPIO pins (uses four pins for 16 addresses); firmware-assigned ID stored in flash.

Rationale: The requirement was explicitly that node ID must not be firmware-only — six physically identical boards need to be distinguishable without reflashing, and a board swapped in the field must take on the identity of the joint it is installed in.

One ADC pin versus four GPIO is the entire point on a pin-constrained device.

Trade-off accepted: The ladder response compresses at high codes — the gap between the two highest codes is on the order of 14 mV — so 1 % resistors, oversampling, and a boot-time-only read are all required rather than optional.

Source impedance reaches roughly 100 kΩ at one extreme, which forces the maximum ADC sampling time on this channel. Acceptable because it is read once, before PWM is active, so switching noise is entirely absent.

Both endpoints are deliberately reserved as unprogrammed or fault codes so that a missing resistor is detectable rather than silently valid.

Status: CONFIRMED. The full 16-level voltage table still needs checking for worst-case adjacent separation against 1 % tolerance plus ADC noise.

### D-25 — Single XT60 with harness Y-splitting, rather than two for daisy-chaining

Decision: One XT60 power connector per board. Bus distribution happens in the harness.

Alternatives considered: Two XT60 connectors per board for true daisy-chaining — the Rev B decision.

Rationale: Y-splitting in the harness is lighter than carrying a second connector on every one of six joints, and it moves current-carrying junctions out of the board.

Trade-off accepted: Harness complexity increases and the bus topology becomes a property of the cable assembly rather than of the boards. A daisy-chain would have been self-documenting; a Y-harness needs its own drawing.

Status: CONFIRMED. Note that all bulk-capacitance sizing assumes the worst-case chain position — the board with the most cumulative wiring impedance — because all six boards share one design and none gets a ripple-current discount.

### D-26 — Standardised connector ecosystem

Decision: JST-GH for signal connectors, XT60 for power, USB-C for the debug and configuration interface, with pinouts aligned to existing robotics ecosystem conventions.

Rationale: Aligning with the conventions used by ODrive, moteus, and the drone autopilot ecosystem means off-the-shelf sensors and cables plug in without custom harnesses. The recurring principle taken from all three ecosystems and applied consistently here: connector supply voltage and bus logic level are always independent decisions — a 5 V pin on a connector never implies 5 V logic.

Trade-off accepted: JST-GH is not the most robust connector family available for a vibrating limb; it was chosen for compatibility rather than for retention force.

Status: CONFIRMED.

### D-27 — USB-C to a UART bridge, not to the MCU's USB peripheral

Decision: USB-C connector feeding a CH340X USB-to-UART bridge into the MCU's UART.

Alternatives considered: Native USB on the MCU.

Rationale: Frees the MCU's USB peripheral and its clock accuracy requirement entirely, which in turn removes any competing constraint on the crystal decision in D-18. A UART bridge is also simpler to bring up and needs no host-side driver work.

Trade-off accepted: An extra IC and its supply, no USB-native features such as firmware update over DFU, and the automatic-reset and boot-select lines are not allocated — the boot-select pin is occupied by a CAN signal, so auto-boot is unavailable regardless.

The bridge's transmit and receive orientation is a classic silent error and needs explicit verification: the bridge's TXD must land on the MCU's UART receive.

Status: CONFIRMED.

### D-28 — CAN common-mode choke and SPI series damping

Decision: Add a common-mode choke on the CAN lines and series damping resistors on off-board SPI signals.

Alternatives considered: Direct connection from IC to connector, which was the original schematic.

Rationale: CAN is differential, but real-world imbalance — unequal driver edges, trace-length mismatch, connector and cable asymmetry — converts differential signal into a common-mode component, and that component both radiates and admits external noise. The transceiver here sits close to an inverter switching at 40 kHz with high dv/dt, and the harness runs alongside motor phase leads inside a robot leg. This is close to a worst case for common-mode noise.

Trade-off accepted: A choke must be selected and placed correctly or it can create ringing under bus-fault conditions, exposing the transceiver to transients outside its operating range. It is not a free addition.

Status: CONFIRMED.

### D-29 — ESD protection consolidated onto as few part numbers as possible

Decision: Standardise on a small set of TVS arrays — a dual-channel USB-oriented part used wherever it fits, and a CAN-FD-specific part on the bus lines — rather than a bespoke selection per connector.

Alternatives considered: A single part number across every interface including USB high-speed data lines.

Rationale: Fewer line items, fewer footprints, and fewer opportunities for a substitution error. The design rules established during that review were: correct ordering of the OR-ing diode and TVS, chassis versus signal ground separation at the connector, clamp voltage matched to the rail it protects, and per-part pinout and capacitance checked rather than assumed.

Trade-off accepted: A literal single-part BoM was rejected: using a CAN-oriented TVS on USB data lines cannot be validated from datasheet comparison alone and would need eye-diagram compliance testing. Consolidation stops where signal integrity begins.

Status: CONFIRMED in principle, with several connector-level items still open — verification of one TVS part number that could not be found in any distributor database, and whether sensor supply pins on the encoder connector need protection in addition to the four signal lines.

# 9. Logic Power Tree

### D-30 — Two-stage step-down plus a separate analog LDO

Decision: Bus to 5 V by a wide-input synchronous buck; 5 V to 3.3 V digital by a second buck; 5 V to 3.3 V analog by a dedicated LDO. Rails sequenced by chaining power-good outputs.

Alternatives considered: A single bus-to-3.3 V converter; a linear regulator from the bus (thermally impossible at 50 V input); sharing one 3.3 V rail across digital and analog.

Rationale: A single-stage converter from 50 V to 3.3 V has a very small duty cycle and poor transient behaviour. Two stages keep both converters in a comfortable range and provide a 5 V rail that the transceiver, the UART bridge, and connector supply pins all need anyway.

The analog rail is separate because the ADC reference and analog supply must not share impedance with digital switching returns. This is the same reasoning that drives the grounding strategy in D-33.

Sequencing was analysed and found not to be a damage risk — no ordering between the driver supply, digital supply, and analog supply will destroy anything. What sequencing actually buys is a guarantee that the gate driver is never live and armed while the MCU's PWM state is undefined.

Trade-off accepted: Three regulators instead of one: more parts, more area, more quiescent draw.

The real risk is not ordering but the pre-boot window. Bus voltage goes live tens of milliseconds before the MCU boots. The gate driver's internal 100 kΩ pull-downs are too weak to rely on against flux residue, probing, or partial population, so external 10 kΩ pull-downs are required on the driver enable, the calibration pin, and all six PWM inputs. The fault and chip-select pull-ups must go to the main 3.3 V rail and never to the driver's own generated supply, which dies whenever the driver is disabled.

Status: CONFIRMED. Note that the specific buck part changed between revisions — earlier documentation names an 80 V-rated device, while the Rev 1 review references a different part number. This should be reconciled before release.

### D-31 — 5 V rail regulation point — an open error

Decision: Not yet resolved.

Alternatives considered: Move the feedback tap after the OR-ing point, or replace the diode with a proper power multiplexer.

Rationale: A series diode sits in the 5 V path for OR-ing with USB bus power, and the converter's feedback divider taps before that diode. The regulated node is therefore at 5.02 V while the actual 5 V rail lands around 4.6 to 4.75 V. The transceiver and the UART bridge both specify a 4.5 V minimum, so the rail is inside specification with almost no margin, and the diode carries full rail current continuously.

Trade-off accepted: A power multiplexer is the clean answer and costs a part. Moving the feedback tap is free but makes the regulation point depend on which source is present.

Status: OPEN. Listed in Section 14.

### D-32 — Status LEDs driven directly from GPIO

Decision: Two status LEDs on the 3.3 V rail with series resistors, driven by open-drain GPIO. No buffer transistors.

Alternatives considered: Open-drain MOSFET buffers, which is what an earlier revision carried; driving from the 5 V rail.

Rationale: At roughly 4 mA per LED against a 20 mA per-pin sink limit, and under 8 mA aggregate, the MCU drives these directly with large margin. Open-drain configuration means the pull-up comes from the rail rather than from an internal driver, so there is no rail-voltage conflict. The buffers existed to solve a voltage mismatch that disappeared when the LEDs moved to the 3.3 V rail.

Trade-off accepted: About 4 mA is dim for a status indicator; a smaller series resistor would brighten it. Deliberately left dim because these are bench-debug indicators, not user-facing status.

Status: CONFIRMED. This is recorded as an example of a component removed because the reason for it had quietly evaporated — the same pattern as the gate diode in D-07.

# 10. Regeneration and Brake Chopper

### D-33 — No brake chopper on the board; footprint reserved, unpopulated

Decision: Do not populate a brake chopper. Reserve the footprint and the connector provision.

Alternatives considered: An on-board brake chopper FET and resistor; an external chopper on a separate power distribution board; relying entirely on the battery to sink regeneration.

Rationale: The verdict rests on gear ratio. Below roughly a 20:1 reduction, the regenerated energy from a single joint decelerating a 50 cm limb is within what the battery and bulk capacitance can absorb. Above that, reflected inertia grows to where a chopper becomes mandatory.

This reverses an earlier and more conservative position, on the strength of the physical argument rather than on convenience.

Trade-off accepted: The decision is conditional on a mechanical parameter that is not yet frozen. If the gear ratio rises, the conclusion inverts and there is no on-board hardware to fall back on — hence reserving the footprint unconditionally.

There is also a system-level exposure the single-board analysis does not capture. Six joints on a shared bus can regenerate simultaneously — a landing is exactly that event — and a bus disconnect during that moment aggregates roughly six times a single board's worst-case energy through one connection. The SPICE bench produced a 154 V excursion for a three-board case with a battery-management disconnect mid-regeneration. That is a system-level protection question, not a per-board one, and it is not closed.

Status: PROPOSED, conditional on gear ratio. Interacts with D-05 and D-19.

### D-34 — Fault-state behaviour: coast, not brake

Decision: On a detected fault the inverter goes to a high-impedance state and the motor coasts.

Alternatives considered: Active short of all low-side switches as the fault state.

Rationale: A hard low-side short at speed drives back-EMF into the phase resistance — on this motor, roughly 19 V into approximately 100 mΩ, which is on the order of 180 A. That exceeds both the device and motor ratings. Braking by shorting must therefore be current-limited and PWM-modulated, which requires firmware to be alive — so it cannot serve as a hardware backstop.

Trade-off accepted: The limb free-falls on a fault. If uncontrolled limb drop is a hazard for the application, a mechanical fail-safe brake is required, and that is outside the scope of the electrical design. A footprint and GPIO for a mechanical brake driver have been recommended as a reserved, unpopulated provision.

Status: CONFIRMED, with the mechanical brake provision open.

# 11. Layout Strategy

Layout has not been executed. This section records the constraints that were derived during schematic work and that layout must honour, together with the reasoning behind them, so that the constraints survive into whoever does the layout.

## 11.1 Stackup and board specification

Parameter | Value | Reason
Layer count | 6 | Two full ground planes plus the routing capacity a mixed-signal power board needs. An earlier 4-layer proposal was superseded.
Stackup | Sig/Pwr · GND · Sig/Pwr · Sig/Pwr · GND · Sig/Pwr | Layer 2 ground must be solid and unbroken beneath the entire power stage.
Copper | 2 oz outer, 1 oz inner minimum | Set by phase current, not by routing density.
Phase trace width | 3.5 mm minimum at 2 oz, 10 A, 10 °C rise | Derived, not chosen.
Bus rail width | 3.0 mm minimum | Same derivation.
Thermal vias | 0.3 mm filled and capped via-in-pad, ≥ 9 per device | Via-in-pad required because the thermal path is the exposed pad.
Back copper per FET | ≥ 200 mm² exposed | Supports the 50 °C/W assumption used in the thermal analysis.
Surface finish | ENIG | Fine-pitch ICs and shelf life.
Board area | OPEN | Was 80 × 80 mm maximum, ~70 × 60 mm minimum for the full BoM. Now gated by the FET package decision in D-06.
Target mass | Under 50 g | Six of these hang on a cat-scale leg.

## 11.2 The single most important layout variable

Commutation loop area. The double-pulse simulation showed drain overshoot rising with loop inductance, but showed negative gate ringing rising far more sharply — from approximately zero at 2 nH to about −4.9 V at 80 nH. Gate-oxide stress and false turn-off therefore appear well before the drain waveform looks alarming on a scope. The loop from bulk capacitor through the high-side device, the switch node, the low-side device, and back to ground must be as physically tight as the board allows, and this takes precedence over routing convenience everywhere it conflicts.

Placement priorities, in order: bulk capacitors adjacent to the half-bridges rather than routed to them; MLCCs at each half-bridge input pin; charge-pump capacitors immediately adjacent to the driver; solid ground beneath the entire power stage; local driver decoupling tight to the IC; gate resistors at the MOSFET gate pins, never routed away from the device.

## 11.3 Ground domain strategy

Three domains, joined at exactly one star point located near the shunt resistors, between the shunts and the gate driver:

- Power ground — high di/dt: MOSFET sources, shunt returns, the driver's power ground pin.
- Analog ground — the driver's analog ground pin, current-sense filter capacitors, divider returns.
- Digital ground — MCU, transceiver, regulator output capacitor returns.

The gate driver explicitly provides separate analog and power ground pins. Honouring that separation in copper is mandatory: merging them anywhere other than the star point injects current-sense amplifier offset error, which corrupts the current feedback and therefore the torque control directly. This is described in the review record as the single most common failure mode of FOC boards.

A note on the apparent tension with D-14: the guidance there argues against splitting copper for the analog rail and in favour of controlling return paths by placement. The two are consistent. Splitting a ground plane arbitrarily creates slots and diverts return current; honouring a device's own documented ground pin separation at a defined star point is a different operation. The distinction is whether the split is defined by the silicon or invented by the designer.

## 11.4 Chassis isolation

Chassis ground is isolated from signal ground and coupled at the mounting holes through 1 nF / 1 kV capacitors. Two findings from the layout review are recorded because both are easy to get wrong invisibly:

- Any ESD discharge path routed as a thin trace through a via adds parasitic inductance exactly where it is least affordable. Discharge paths should be direct low-inductance copper on a single layer, with vias minimised.
- The isolation moat must be cut in the inner ground planes as well as in top copper. If chassis stitching vias pass through inner layers where the ground pour has not been cleared, the carefully isolated chassis is silently shorted back to signal ground and the isolation exists only on the drawing.

## 11.5 Design for test

Test point coverage was specified by category rather than ad hoc: one per power rail near its source; each phase voltage output; post-shunt nodes for gain calibration without a motor connected; the amplifier outputs to verify gain settings; all six gate signals for switching waveform verification; the oscillator pins; CAN at the connector; and ground references every 30 mm across the board so that probe return inductance does not corrupt measurements. Test points are 1 mm exposed pad with a ground reference within 5 mm.

## 11.6 Design for manufacture

Fiducials were specified, then removed from the schematic at some point, and need reinstating — three global fiducials plus local fiducials on the fine-pitch gate driver. The assembly house needs them. Other items on the record: pin-1 indicators on all IC footprints, polarity marking on diodes and polarised capacitors, connector silkscreen with pin 1 and signal names, mounting-hole copper keepouts, and board revision and date code in copper or silkscreen.

# 12. BoM Consolidation

Consolidation was performed once the design was stable, as a deliberate late step. The governing principle was that a line item is only worth removing if removing it does not compromise the reason the part was chosen. Several available consolidations were explicitly declined on that basis, and those refusals are as informative as the accepted ones.

## 12.1 Techniques applied

Technique | Example | Outcome
Merge duplicate rows | The hot-swap sense resistor and the three phase shunts were already the identical part number split across two BoM rows. | Free line-item saving with zero design change. Done first.
Parallel synthesis | Building a 49.9 kΩ ladder resistor from two 100 kΩ parts already on the board. | 0.2 % shift, invisible against 16-level quantisation. Trades one placement for a whole line item.
Series synthesis | Building a 37.3 kΩ divider leg from two values already on the board. | Removes a line item and simultaneously fixes a working-voltage violation — a single 0402 at that value would see about 53 V against a 50 V limit.
Footprint substitution | Chassis stitching links moved from 0603 to the 0805 zero-ohm part already used elsewhere. | Pure line saving; these links carry no current so footprint size is electrically irrelevant.
Dielectric upgrade | X5R to X7R on a shared rail capacitor line. | X5R is only characterised to 85 °C. On an inverter board next to a six-FET bridge that is a real derating risk. Same single line item, better part.

## 12.2 Consolidations deliberately declined

Part | Why it was left alone
Hot-swap divider legs | These set the undervoltage and overvoltage trip points. The nearest synthesis from existing values lands about 2.5 % off — directly on a trip threshold. Not worth one line item.
100 V 1 µF capacitors vs 16 V 1 µF | Folding seven low-voltage parts into the 100 V line would save one row and raise unit cost roughly tenfold on all seven, plus grow footprints. Rejected.
USB-C configuration pull-downs | The value and tolerance are mandated by the USB Type-C specification. Not substitutable.
CAN split termination resistors | Value is set by bus characteristic impedance.
Gate series resistors | Value is set by the I_DRIVE and dv/dt work, not by BoM economics. Kept at 0805 for lower loop inductance and a wider link.
High-voltage divider top legs | Kept as series pairs specifically so no single 0402 body exceeds its working-voltage limit. Collapsing to a single part would be a latent reliability defect, not a saving.

## 12.3 Consequences to propagate

Two of the accepted changes alter divider ratios and therefore change firmware scaling constants for the bus voltage reading. This is recorded here because it is exactly the kind of change that is made for BoM reasons and then silently breaks a calibration constant nobody re-derived.

## 12.4 Description formatting for assembly

Passive descriptions were regenerated into the assembly house's own attribute-string convention, parsed from the schematic value field rather than typed, so that part matching against the supplier library works reliably. Two deliberate exclusions: non-passive parts keep their original schematic description, because no standardised attribute string exists for those categories and a fabricated one would be worse than the real text; and capacitor tolerance is omitted rather than invented, because the schematic value field never specified it.

# 13. Corrections to the Design Record

Each of the following was believed, acted on, and later found to be wrong. They are recorded in full because a design record that shows only correct conclusions is not a record of engineering.

### C-1 · Gate driver charge pump capability

Earlier figure: 10–15 mA. Corrected to: 25 mA at the operating bus voltage. The lower values apply only at low supply voltage where the doubler is strained, not at a 44–50 V bus. The correction meaningfully relaxes the gate-charge budget and widened the viable MOSFET field.

### C-2 · The gate charge ceiling

Earlier statement: 100 nC per FET at 40 kHz with 2× margin. Corrected to: 100 nC is the 1× figure. The 2× ceiling is approximately 52 nC. Re-deriving: 25 mA divided by (2 × 6 × 40 kHz) gives 52 nC. The practical impact on this design is nil — the selected FET draws 13.2 mA and achieves 1.9× margin — but the rule of thumb was wrong and would have mis-screened a future substitution.

### C-3 · Shunt resistor value

Earlier instruction: critical action item to change the shunts from 5 mΩ to 1 mΩ. Retracted. That instruction was generated during a MOSFET-selection exercise at a 40 A RMS operating point, where 5 mΩ would dissipate 8 W in a 3 W part. At the frozen 10 A design point the change is unnecessary and actively harmful — it discards a factor of five in sense resolution for no thermal benefit. The lesson recorded at the time: an action item carried forward without its operating-point context is worse than no action item.

### C-4 · Gate driver ordering code

Earlier specification: DRV8323SRTVR. Corrected to: DRV8323SRTAR. RTV is the 32-pin 5×5 package used only on the DRV8320; the 40-pin 6×6 WQFN part is RTAR. The schematic symbol was correct throughout — only the written guidance was wrong.

### C-5 · MOSFET selection metric

Earlier basis: lowest R_DS(on) available in the 100 V class. Corrected to: figure of merit, R_DS(on) × Qg. See Section 3.1. The lowest-R_DS(on) candidate had the highest total loss at the actual operating point.

### C-6 · Snubber requirement

Earlier requirement: every half-bridge shall include an RC snubber; resistor power rating to be re-verified at the final switching frequency. Superseded, not closed. The drain-source snubber was removed entirely rather than sized, and replaced by gate-side slew control. This is defensible but unverified, and it converts a sizing task into a validation task. The distinction between an item that was closed and an item that was superseded matters — this one is still owed a simulation.

### C-7 · Brake chopper

Earlier position: a brake chopper or local clamp is likely required. Revised to: not required below approximately 20:1 gearing; populate the footprint, leave unpopulated. Reversed on the strength of a physical argument about reflected inertia rather than on convenience. The reversal is conditional and reverts if the gear ratio rises.

### C-8 · Bulk capacitance note on the schematic

The schematic sheet note states 300 µF total; the actual populated bank is five 100 µF parts, 500 µF. The MLCC count and the derated effective figure in the same note are also stale. This matters beyond tidiness: the startup and inrush calculations on the input-protection sheet consume that number, so the correction has to propagate rather than just be edited in place.

### C-9 · Documentation state

At the time of the Rev 1 review, the cover page index still listed placeholder sheet names, the block diagram and power sequencing sheets were untouched template pages, the title block was default text, and the revision history was blank. Recorded here as a finding rather than omitted, because for a board intended as a portfolio and open-source artefact the cover sheet is the first thing a reviewer forms an opinion from — and it was the weakest part of the package.

# 14. Open Items at Time of Writing

## 14.1 Blockers — must be resolved before layout

ID | Item | Why it blocks
B1 | TVS clamping voltage exceeds the gate driver's absolute maximum rating (D-03). | No clean part exists at this bus voltage. The resolution may be a different clamp topology, added series impedance, or an explicit decision to accept the gate driver as sacrificial — all of which change the schematic.
B2 | Gate driver voltage class: keep the 60 V part or move to the 100 V sibling (D-04). | Not pin-compatible. Now or never before layout.
B3 | Generator-mode hazard with the hot-swap switch between battery and driver supply (D-05). | May require a clamp, a different hot-swap variant, or a chopper — all schematic changes.
B4 | Hot-swap pass FETs Q1/Q2 have no manufacturer part number assigned. | Cannot be sized for SOA, cannot be laid out, cannot be ordered.
B5 | Switching frequency not frozen (D-09). | Snubber validation and bulk-capacitance sizing both consume it.

## 14.2 High priority

- Hot-swap current limit sits below the stated maximum input current — the sense resistor gives roughly 17 A against a 20 A stated rating, and the sheet contradicts itself. Verify whether the threshold used is the minimum, typical, or maximum of the tolerance band; if it is the maximum, the worst-case trip is materially lower still.
- The hot-swap power-good output terminates in a local label with no hierarchical connection. The MCU has no visibility into input-stage state and no way to command it. Route it to a GPIO, and consider MCU control of the undervoltage pin as a software-commanded shutdown.
- Gate driver enable and calibration pins float at power-up. Add 10 kΩ pull-downs to both — before the MCU configures its GPIOs, enable state is undefined and a floating calibration pin can put the amplifiers into calibration mode.
- 5 V rail regulation point and OR-ing diode arrangement (D-31).
- Replace the ceramic resonator with quartz (D-18).
- No hardware safe-torque-off path independent of firmware and CAN (D-19).
- Charge-pump storage capacitor is rated 16 V across an 11 V differential; X7R DC-bias derating removes a large fraction of it. Move to 25 V — same case size, no cost.
- Reinstate fiducials, three global plus locals on the gate driver.
- Complete the LTspice half-bridge validation — now higher priority than before, because the snubber was removed rather than sized (C-6).

## 14.3 Verify

- Transceiver ordering code — the variant in the project files differs from the schematic, and pin 5 function differs between variants.
- UART bridge transmit and receive orientation at the bridge end.
- CAN node-ID ladder: compute all 16 levels and check worst-case adjacent separation against tolerance plus ADC noise.
- MLCC effective capacitance under DC bias, from the manufacturer's own curve rather than the current estimate.
- Add one decoupling capacitor per MCU supply pin — there are currently fewer capacitors than pins.
- Reconcile the buck converter part number between the earlier documentation and the Rev 1 schematic (D-30).
- Resolve the duplicate and orphan net names on the architecture sheet before running electrical rules check.
- Confirm what was on the schematic sheet missing from the Rev 1 export.

## 14.4 Deferred by choice

- MOSFET package reconsideration — TOLL to a smaller PQFN — for board area and mass (D-06). Must be settled before layout since it sets board size.
- On-board encoder reinstatement (D-21). Deferred, with mitigations available that do not require redesign.
- System-level contactor and its supply architecture (D-19).
- Motor-mount thermal isolation — a mechanical decision, reasonable to defer to layout.
- Mechanical fail-safe brake driver — footprint and GPIO reserved, unpopulated.
- Gear ratio, limb mass, and board size — external mechanical inputs that several electrical conclusions depend on.

# 15. References

The reasoning in this document was checked against the following. Readers are encouraged to verify the arguments against these sources rather than taking this document on trust.

## 15.1 Semiconductor and application notes

- TI SLVSDJ3D — DRV8323 datasheet. Pin functions, SPI timing, charge pump budget equation, generator-mode description, layout guidelines.
- TI SLVAF66 — motor driver system design, including brake versus coast topology and external active brake circuits.
- TI SLVA714 — understanding I_DRIVE and T_DRIVE in TI motor gate drivers. The reference that justifies or refutes the zero-ohm series gate resistor choice.
- TI SBAA698A — MOSFET literature, for the gate-side versus drain-side dv/dt control argument.
- TI Layout Guide for the DRV832x family.
- TI SLYT202 — understanding PSRR in LDOs; and SBVA042 on whether an LDO actually cleans up switching noise.
- TI SLLA270 — CAN physical layer and oscillator tolerance.
- TI SLVA959 and SLYT512 — layout for motor drive analog sensing.
- TI application note on CAN bus common-mode chokes and EMC.
- Infineon OptiMOS 6 family documentation and the ISC030N10NM6 datasheet.
- Infineon and vendor SiC snubber design application notes.

## 15.2 Microcontroller

- ST DS12589 — STM32G431 datasheet. LQFP64 pinout, pin definitions and I/O structure table (authoritative for 5 V tolerance claims), alternate function table.
- ST RM0440 — STM32G4 reference manual. Power control register for the dead-battery disable bit, flash option bytes, timer break inputs, ADC dual injected simultaneous mode.
- ST AN2867 — oscillator design guide. Load capacitance sizing and crystal selection methodology.
- ST AN2834 — how to get the best ADC accuracy in STM32 microcontrollers. Includes a PCB layout section written for this part family.
- ST AN4013 — cross-series timer overview: complementary PWM, dead time, break.
- ST AN4899 — GPIO configuration for unused and low-power pins.

## 15.3 Sensors, transceivers and protection

- AMS AS5047P DS000324 — pin assignment, SPI mode and timing, 3.3 V versus 5 V wiring minimums.
- TI SLLSET0D — TCAN1051 datasheet, pin functions by variant.
- TI SNVS566 — LM5069 datasheet: current limit threshold, power limiting, timer sizing, shutdown and restart configuration.
- ST USBLC6 series datasheets; NXP PESD2CANFD24V datasheet.
- Murata CERALOCK application notes and the CSTNE8M00G520000R0 datasheet; NDK NX3225GA datasheet for the quartz alternative.
- Vishay NTCLE100E3 series and Murata NCP18XH103 datasheets for thermistor R-T curves.

## 15.4 Standards

- IEC 61000-4-2 — ESD immunity, the system-level gun test.
- ISO 10605 — automotive ESD test, for comparison of test conditions.
- IEC 60204-1 — stop categories, referenced for the e-stop architecture.
- IEC 61800-5-2 — safe torque off terminology, if the e-stop design is described formally.
- ISO 11898 — CAN bit timing, for the oscillator tolerance budget.
- USB Type-C specification — configuration channel pull-down value and tolerance.

## 15.5 Open-source reference designs consulted

Project | What it was consulted for
ODrive (ODriveHardware, ODrive S1) | Closest architectural match. Bus voltage and gate driver class precedent, regeneration and brake resistor handling, watchdog behaviour, connector conventions.
mjbots moteus | Apache-licensed full KiCad source, CAN-FD servo controller with multiple hardware revisions to compare. Auxiliary connector pin selection methodology and default pull-up behaviour.
ODRI (Open Dynamic Robot Initiative) | Distributed actuator architecture and the placement of e-stop handling in the power board rather than the compute board.
OpenPodcar | Heartbeat timeout precedent and the physical relay upstream of the electronics.
CANable 2.0, CANvas, RudolphRiedel USB_CAN-FD | Open CAN adapter designs, consulted for TVS selection rationale on CAN lines.
PX4 / Dronecode and Auterion peripheral documentation | Connector bus conventions, 3.3 V bus convention, internal pull-up practice.

## 15.6 General references

- Henry Ott, Electromagnetic Compatibility Engineering — power distribution filtering and mixed-signal PCB layout, return current paths.
- Analog Devices MT-031 — grounding data converters, and the case against splitting ground planes.
- Analog Devices MT-101 — decoupling techniques.
- Rick Hartley, How to Achieve Proper Grounding — particularly on why plane cuts cause more problems than they solve.
- TI BPRA048 — Clarke and Park transforms.
- SimpleFOC documentation, FOC theory section.
- KiCad documentation at docs.kicad.org — zone priority and fill behaviour, hierarchical sheet and global label semantics.
- JLCPCB capability documentation — manufacturing and assembly constraints.

# 16. Lessons

Written for the reader of the repository rather than for the designer. These are the generalisable observations, not the board-specific ones.

### Select on the metric that binds, not the metric that is famous

R_DS(on) is the number every MOSFET is marketed on, and at this current and switching frequency it was the wrong one. The binding constraints were gate charge, against the driver's charge pump budget, and switching loss, against total dissipation. The lowest-R_DS(on) candidate had the highest total loss. Identifying which constraint actually binds is the whole content of the first-principles stage.

### An action item without its operating point is a hazard

The retracted shunt instruction (C-3) was correct when written, at a 40 A operating point, and harmful when applied at 10 A. Action items that survive a change of operating point without carrying that context with them will eventually be applied in the wrong place. Every carried-forward item should state the assumption it depends on.

### Check the note against the symbol

The ordering code error (C-4) survived several revisions because the written note and the schematic symbol were never compared. Any fact that appears in two places will eventually disagree in two places.

### When the reason for a component evaporates, delete the component

Two parts were removed for the same reason: the gate-network diode existed to solve an asymmetry the gate driver already handles internally, and the LED buffer transistors existed to solve a voltage mismatch that disappeared when the LEDs moved rails. Neither was wrong when added. Both survived past their justification. Re-checking why a part is there, rather than only whether it works, is a distinct review pass and worth doing explicitly.

### Removing a component is not the same as sizing it

The snubber decision (D-07, C-6) is defensible engineering, but it closed a requirement by deletion rather than by analysis. That converts a sizing task into a validation task and raises rather than lowers the priority of simulation. Requirements closed by removal deserve more scrutiny than requirements closed by satisfaction, not less.

### Over-provisioning is a cost, not free margin

Six TOLL packages for a stage dissipating under a watt is roughly 700 mm² of board bought to solve a problem the design does not have — and on a robot leg, board area is mass, and mass is the thing the whole machine is fighting. Margin that costs nothing is margin worth keeping; margin that costs the primary system constraint is a design defect wearing a reassuring disguise.

### The failure that gets you is the connector, not the silicon

The most likely field failure in this design, on the review record, is not a semiconductor at 1.2× voltage margin. It is a synchronous serial bus running over an unshielded cable through a moving joint next to an inverter (D-21). The electrically interesting risk and the actually probable risk are frequently not the same risk.

### Two mechanisms, two timescales

The e-stop analysis (D-19) converged on the same structure every surveyed open-source project had arrived at independently: a fast mechanism that makes the system safe, and a slower one that makes it graceful, triggered together but never conflated. The tempting single mechanism — the pin the manufacturer advertises for remote shutdown — was the wrong answer for exactly this reason.

End of document DDR-001

FOC Motor Controller — Design Rationale and Decision Record DDR-001 Rev 1

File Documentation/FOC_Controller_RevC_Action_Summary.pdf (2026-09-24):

# FOC Motor Controller — Rev C Action Summary

Consolidated design review, calculations, and pre-layout checklist
Target motor: ODrive M8325s 100KV | Gate driver: DRV8323S | MCU: STM32G431CBU6

## 0. How to use this sheet

Each section states the decision or finding, then lists action items with checkboxes. Work top-down: Section 1 (corrections to earlier advice) changes numbers used elsewhere, so read it first. Priority key: CRIT = blocks power-on; HIGH = blocks layout; MED = should be in Rev C; LOW = optional / next revision.

## 1. Corrections to Earlier Guidance (read first)

## 1.1 Charge pump current was understated

Earlier in this project I stated the DRV8323 charge pump supplies roughly 10-15 mA at a 50 V bus. That was wrong. The DRV8323 datasheet states the charge pump regulates to V_VM + 11 V and supports an average output current of 25 mA. The lower figures (15 mA at V_VM = 8 V, 10 mA at 6 V) apply only at low bus voltages where the doubler is strained. At a 44-50 V bus, use I_VCP = 25 mA.
Consequence: the gate-charge ceiling roughly doubles versus what I previously told you. The IPT015N10N5 is less marginal than I implied, and 40 kHz becomes a realistic design point with the right MOSFET.

## 1.2 LMR38010FDDAR input rating

You confirmed from the datasheet that this part supports 80 V input. The earlier flag raised against it is withdrawn - no change needed for a 60 V bus. No action required.

## 1.3 Values still marked as estimates

- Q_g figures for ISC022N10NM6, ISC030N10NM6, ISC060N10NM6 and the BSC-series parts were scaled from the confirmed ISC027N10NM6 value (58 nC). They are estimates and must be read off each datasheet before ordering.
- M8325s phase resistance, phase inductance, and current rating are not published by ODrive. Every current/torque/power figure in this sheet is inverter-limited, not motor-verified.
- Kt = 8.27 / KV = 0.0827 Nm/A is a first-order estimate from the KV rating, not a measured value.

## 2. Design Point and Derived Requirements

## 2.1 Motor and bus (published / derived)

Parameter | Value | Source
KV | 100 RPM/V | ODrive published
Pole pairs | 20 | ODrive published
Diameter / weight | 92 mm / 840 g | ODrive published
Kt (estimate) | 0.0827 Nm/A | 8.27 / KV - first order
Phase R / L | NOT PUBLISHED - measure | must characterise
Bus (12S LiPo) | 42.0 V cutoff / 44.4 V nom / 50.4 V full | 12 x 3.5/3.7/4.2 V
V_phase,rms max (SVPWM) | 20.6 V at 50.4 V bus | V_bus / (sqrt3 x sqrt2)

## 2.2 Switching frequency - driven by 20 pole pairs

f_elec = (RPM / 60) x 20. At 1000 rpm = 333 Hz; 2000 rpm = 667 Hz; 3500 rpm = 1167 Hz. Using a rule of thumb of at least 20 PWM cycles per electrical cycle, full speed needs f_PWM >= 25 kHz. Design target 40 kHz for headroom, ultrasonic operation, and lower current ripple.

## 2.3 Gate charge ceiling (corrected)

Sinusoidal 180 deg commutation, DRV8323 datasheet Eq. 10: I_VCP > 3 x Qg x f_PWM Qg_max = I_VCP / (3 x f_PWM), with I_VCP = 25 mA:
20 kHz -> 417 nC 30 kHz -> 278 nC 40 kHz -> 208 nC 45 kHz -> 185 nC
Design target with 2x margin at 40 kHz: Qg <= 100 nC
TI calls this a quick calculation, so do not design to the edge. A 200 nC part works at 40 kHz on typical silicon but sits at the limit on worst-case Qg.

## 2.4 Current target and the loss inversion

To make full use of this motor, target ODrive S1/Pro class current: 40 A RMS continuous, 80 A peak. Loss per MOSFET at 40 A RMS, 40 kHz, 50 V bus (Rds(on) derated 1.5x for 125 C junction, ~50% duty, I_DRIVE = 1 A):

Rds(on)=2.24 mOhm -> P_cond 2.69 W + P_sw 1.58 W = 4.27 W Rds(on)=2.70 mOhm -> P_cond 3.24 W + P_sw 1.36 W = 4.60 W Rds(on)=1.50 mOhm -> P_cond 1.80 W + P_sw 3.85 W = 5.65 W (IPT015N10N5)
Note the inversion: the ultra-low-Rds(on) IPT015N10N5 has the WORST total loss at 40 kHz because its Qgd is 2-3x higher. Switching loss dominates conduction loss at this current and frequency. Select on Figure of Merit (Rds(on) x Qg), lower is better
- not on Rds(on) alone.
Done | Action item | Priority | Where
[ ] | Fix f_PWM in firmware/CubeMX at the chosen value (40 kHz target) and record it on the schematic | HIGH | TIM1 / schematic note
[ ] | Measure M8325s phase resistance (4-wire, line-to-line / 2) and phase inductance (LCR) | HIGH | bench, pre-tuning
[ ] | Verify Kt empirically once the motor spins; do not rely on 8.27/KV for final torque claims | MED | bench
[ ] | Write the Qg ceiling calculation as a text note next to the MOSFETs on the schematic | MED | MOSFETs sheet

## 3. MOSFET Selection

## 3.1 Required specification (derived in Section 2)

Parameter | Requirement | Rationale
V_DS | >= 100 V | 50.4 V bus x ~2 for switching transients
Q_g total @10V | <= 100 nC target; 208 nC hard limit | Charge pump budget at 40 kHz
Q_gd (Miller) | as low as possible, <= 20 nC | Dominates switching loss
R_DS(on) @10V | 2 - 3 mOhm | Conduction loss at 40 A RMS
I_D continuous | >= 80 A (Tc) | Peak current headroom
Package | SuperSO8 5x6 or TOLL | Exposed pad for via-in-pad thermal path
V_GS(th) | >= 2 V | dV/dt parasitic turn-on immunity

## 3.2 Candidates - Tier 1, Infineon OptiMOS 6 (best fit)

Part | V_DS | Rds(on) | Qg | I_D | Package | Availability
ISC022N10NM6 | 100V | 2.24 mOhm max | ~70 nC * | 230 A | SuperSO8 | Infineon / DK
ISC027N10NM6 | 100V | 2.7 mOhm max | 58 nC (conf.) | 192 A | SuperSO8 | Infineon / DK
ISC030N10NM6 | 100V | 3.0 mOhm | ~52 nC * | 179 A (Tc) | PG-TDSON-8 FL | DigiKey, in stock
ISC060N10NM6 | 100V | 6.0 mOhm max | ~30 nC * | 97 A | SuperSO8 | DigiKey ~$3.10
* estimated by scaling from the confirmed ISC027N10NM6 figure - verify from datasheet.

## 3.3 Candidates - Tier 2, OptiMOS 5 (confirmed DigiKey.ca stock)

Part | V_DS | Rds(on) | Qg | Package | Link
BSC040N10NS5 | 100V | 4.0 mOhm | ~60 nC * | PG-TDSON-8-7, 100 A (Tc) | DigiKey.ca
BSC027N10NS5 | 100V | 2.7 mOhm | ~90 nC * | SuperSO8 | Infineon / DigiKey

## 3.4 Candidates - Tier 3, JLCPCB stock (all miss the Qg target)

Part | V_DS | Rds(on) | Qg | JLCPCB | Verdict
GT016N10TL | 100V | 1.3 mOhm | 165 nC | C28405277 | 40 kHz marginal
NCEP023N10LL | 100V | 2.3 mOhm | 240 nC @50V | C2686686 | <= 30 kHz only
NCEP020N10LL | 100V | 2.0 mOhm | 252 nC | C2686687 | <= 30 kHz only
IPT015N10N5 (current) | 100V | 1.5 mOhm | 169 typ / 211 max | - | 40 kHz at the limit
The JLCPCB 100 V TOLL inventory is optimised for 200-360 A battery/BMS applications; none of it has the low-Qg profile this design wants.
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

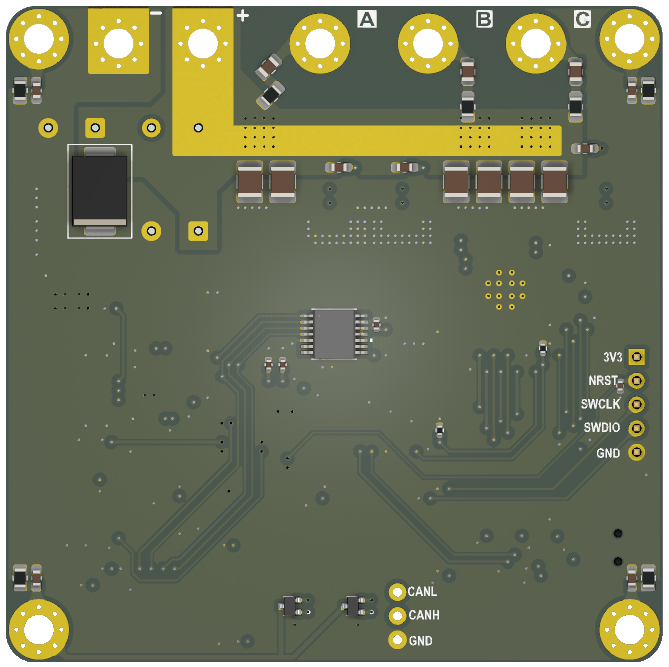
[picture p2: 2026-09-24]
Documentation/FoC Motor Controller Bottom.png

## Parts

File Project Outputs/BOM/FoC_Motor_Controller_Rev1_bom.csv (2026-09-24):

Reference | Value | Datasheet | Footprint | Qty | Description
C4,C5,C40,C43,C44,C47,C48,C50,C51,C52,C59,C80 | 4u7 X7R 100V |  | Capacitor_SMD:C_1210_3225Metric_Pad1.33x2.70mm_HandSolder | 12 | Unpolarized capacitor
C6,C33,C38,C49,C58 | 100n X7R 100V |  | Capacitor_SMD:C_0603_1608Metric_Pad1.08x0.95mm_HandSolder | 5 | Unpolarized capacitor
C7,C10,C15,C17,C20,C24,C31,C41,C79 | 1u X5R 25V |  | Capacitor_SMD:C_0603_1608Metric | 9 | Unpolarized capacitor
C9,C18,C19,C21,C22,C23,C32,C60,C61,C62,C65,C66,C67,C70,C72,C77,C78,C81 | 100n X7R 50V |  | Capacitor_SMD:C_0402_1005Metric | 18 | Unpolarized capacitor
C11,C12,C13,C14,C16 | 22u X5R 16V |  | Capacitor_SMD:C_0805_2012Metric | 5 | Unpolarized capacitor
C25,C26,C27,C42 | 2n2 X7R 50V |  | Capacitor_SMD:C_0402_1005Metric | 4 | Unpolarized capacitor
C28,C29 | 12pF 50V C0G |  | Capacitor_SMD:C_0402_1005Metric | 2 | Unpolarized capacitor
C30,C68 | 47n X7R 100V |  | Capacitor_SMD:C_0603_1608Metric_Pad1.08x0.95mm_HandSolder | 2 | Unpolarized capacitor
C34,C37,C39 | 100uF 100V | https://cdn.sparkfun.com/assets/8/a/4/a/5/Kemet_Capacitor_Datasheet.pdf | Capacitor_THT:CP_Radial_D10.0mm_P5.00mm | 3 | Polarized capacitor, US symbol
C73,C74,C75,C76 | 1n X7R 1kV |  | Capacitor_SMD:C_0603_1608Metric_Pad1.08x0.95mm_HandSolder | 4 | Unpolarized capacitor
D1 | SMCJ51CA | https://www.tme.eu/Document/535c4da69331b5e4fe2b7f8cdcd9eb69/SMCJ_ser.pdf | PCM_Diode_SMD_AKL:D_SMC_TVS | 1 | SMC Bidirectional TVS Diode, 51V, 1500W, Alternate KiCAD Library
D4,D7 | PESD2CANFD24V-K |  | PESD2CANFD24V-UX:TVS_PESD2CANFD24V-UX | 2 | ESD Suppressor Diode TVS Bi-Dir 24V 42Vc Automotive 3-Pin SC-70 T/R
DZ2,DZ3 | MM3Z3V3ST | https://www.tme.eu/Document/59602a643d19bb5d35c4e4c7d37742b4/MM3ZxxxST1G_SZMM3ZxxxST1G.pdf | PCM_Diode_SMD_AKL:D_SOD-323 | 2 | SOD-323 Zener diode, 3.3V, 300mW, Alternate KiCAD Library
J1,J3,J4,J5 | Conn_01x04_MountingPin |  | Connector_JST:JST_GH_BM04B-GHS-TBT_1x04-1MP_P1.25mm_Vertical | 4 | Generic connectable mounting pin connector, single row, 01x04, script generated (kicad-library-utils/schlib/autogen/connector/)
J6 | Conn_01x07_MountingPin |  | Connector_JST:JST_GH_BM07B-GHS-TBT_1x07-1MP_P1.25mm_Vertical | 1 | Generic connectable mounting pin connector, single row, 01x07, script generated (kicad-library-utils/schlib/autogen/connector/)
J7 | Conn_01x05 |  | Connector_PinHeader_2.54mm:PinHeader_1x05_P2.54mm_Vertical | 1 | Generic connector, single row, 01x05, script generated (kicad-library-utils/schlib/autogen/connector/)
J10,J11 | Conn_01x02_MountingPin |  | Connector_JST:JST_GH_BM02B-GHS-TBT_1x02-1MP_P1.25mm_Vertical | 2 | Generic connectable mounting pin connector, single row, 01x02, script generated (kicad-library-utils/schlib/autogen/connector/)
L2 | 10uH 125mΩ 3.2A |  | Inductor_SMD:L_Changjiang_FXL0530 | 1 | Inductor
LED1,LED3,LED4 | LED_0603_Amber |  | PCM_LED_SMD_AKL:LED_0603_1608Metric | 3 | Amber SMD LED, 0603, Alternate KiCad Library
Q3,Q4,Q5,Q6,Q7,Q8 | ISC030N10NM6 |  | ISC030N10NM6:IFX-PG-TDSON-8-36-V | 6 | Insulated-Gate Field-Effect Transistor (IGFET), N-Channel, Enhancement, Body Diode, Pin 1 Source, 2 Source, 3 Source, 4 Gate, 5 Drain, 6 Drain, 7 Drain, 8 Drain, 8 Pins
R10,R72 | 24.9k 1% |  | Resistor_SMD:R_0402_1005Metric | 2 | Resistor
R11,R17,R18,R38,R40 | 10k 1% |  | Resistor_SMD:R_0402_1005Metric | 5 | Resistor
R12,R16,R19 | 100k 1% |  | Resistor_SMD:R_0402_1005Metric | 3 | Resistor
R13,R14,R15 | 56R 1% |  | Resistor_SMD:R_0402_1005Metric | 3 | Resistor
R20,R21,R25,R26,R30,R31,R58 | 0R 1% 1/8W |  | Resistor_SMD:R_0805_2012Metric,Resistor_SMD:R_0805_2012Metric_Pad1.20x1.40mm_HandSolder | 7 | Resistor
R22,R27,R32 | 3mΩ 3W 1% |  | Resistor_SMD:R_2512_6332Metric_Pad1.40x3.35mm_HandSolder | 3 | Resistor
R36,R39,R42,R44 | 2k 1% |  | Resistor_SMD:R_0402_1005Metric | 4 | Resistor
R37 | 10k NTC | https://www.murata.com/-/media/webrenewal/products/thermistor/ntc/ncp/ncp18.ashx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 | PCM_SparkFun-Resistor:R_0603_1608Metric | 1 | Temperature dependent resistor
R41,R62,R65,R66 | 1k 1% |  | Resistor_SMD:R_0402_1005Metric | 4 | Resistor
R45,R46 | 60R4 1% |  | Resistor_SMD:R_0805_2012Metric | 2 | Resistor
R47,R48,R49,R50,R51,R52,R53,R54 | 100R 1% |  | Resistor_SMD:R_0402_1005Metric | 8 | Resistor
R73 | 12.4k 1% |  | Resistor_SMD:R_0402_1005Metric | 1 | Resistor
SW1 | SW_Push_DPDT |  | PCM_SparkFun-Switch:Slide_DPDT_SMD_7.2x3.5mm | 1 | Momentary Switch, dual pole double throw
U1 | AS5047P-ATSM | AS5047P-ATSM | TSSOP14_OSM | 1
U3 | LMR36520ADDAR | https://www.ti.com/lit/gpn/lmr36520 | DDA0008J | 1
U5 | STM32G431RBTx | https://www.st.com/resource/en/datasheet/stm32g431rb.pdf | Package_QFP:LQFP-64_10x10mm_P0.5mm | 1 | STMicroelectronics Arm Cortex-M4 MCU, 128KB flash, 32KB RAM, 170 MHz, 1.71-3.6V, 52 GPIO, LQFP64
U6 | DRV8323SRTAR | https://www.ti.com/lit/gpn/drv8323 | RTA0040B | 1
U7 | TLV75733PDRV | https://www.ti.com/lit/ds/symlink/tlv757p.pdf | PCM_SparkFun-Semiconductor-Standard:WDFN-6_2x2mm | 1 | 1A Low IQ Small Size Low Dropout Voltage Regulator, Fixed Output 3.3V, WSON6
U8 | TCAN1044AVDRQ1 | https://www.ti.com/lit/gpn/tcan1044a-q1 | D0008A-IPC_A | 1
X1 | SMD3225-4 |  | PCM_Crystal_AKL:Crystal_SMD_3225-4Pin_3.2x2.5mm | 1 | SMD Quartz crystal, 4 terminals, 3.2mm x 2.5mm, Alternate KiCad Library

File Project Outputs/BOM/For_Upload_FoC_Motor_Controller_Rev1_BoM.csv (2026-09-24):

Designator | Footprint | Quantity | Value | LCSC Part # | Description
C4,C5,C40,C43,C44,C47,C48,C50,C51,C52,C59,C80 | 1210 | 12 | 4u7 X7R 100V | C2997285 | 100V 4.7uF X7R 1210 Multilayer Ceramic Capacitors MLCC - SMD/SMT ROHS
C6,C33,C38,C49,C58 | 0603 | 5 | 100n X7R 100V | C15725 | 100V 100nF X7R 0603 Multilayer Ceramic Capacitors MLCC - SMD/SMT ROHS
C7,C10,C15,C17,C20,C24,C31,C41,C79 | 0603 | 9 | 1u X5R 25V | C5673 | 25V 1uF X5R 0603 Multilayer Ceramic Capacitors MLCC - SMD/SMT ROHS
C9,C18,C19,C21,C22,C23,C32,C60,C61,C62,C65,C66,C67,C70,C72,C77,C78,C81 | 0402 | 18 | 100n X7R 50V | C77020 | 50V 100nF X7R 0402 Multilayer Ceramic Capacitors MLCC - SMD/SMT ROHS
C11,C12,C13,C14,C16 | 0805 | 5 | 22u X5R 16V | C296720 | 16V 22uF X5R 0805 Multilayer Ceramic Capacitors MLCC - SMD/SMT ROHS
C25,C26,C27,C42 | 0402 | 4 | 2n2 X7R 50V | C77022 | 50V 2.2nF X7R 0402 Multilayer Ceramic Capacitors MLCC - SMD/SMT ROHS
C28,C29 | 0402 | 2 | 12pF 50V C0G | C1547 | 50V 12pF C0G 0402 Multilayer Ceramic Capacitors MLCC - SMD/SMT ROHS
C30,C68 | 0603 | 2 | 47n X7R 100V | C469624 | 100V 47nF X7R 0603 Multilayer Ceramic Capacitors MLCC - SMD/SMT ROHS
C34,C37,C39 | CP_Radial_D10.0mm_P5.00mm | 3 | 100uF 100V | C42371899 | 100uF 100V Aluminum Electrolytic Capacitors - Radial ROHS (verify ESR/ripple spec before ordering)
C73,C74,C75,C76 | 0603 | 4 | 1n X7R 1kV | C696365 | 1kV 1nF X7R 0603 Multilayer Ceramic Capacitors MLCC - SMD/SMT ROHS
D1 | D_SMC_TVS | 1 | SMCJ51CA | C151288 | SMC Bidirectional TVS Diode, 51V, 1500W, Alternate KiCAD Library
D4,D7 | TVS_PESD2CANFD24V-UX | 2 | PESD2CANFD24V-K | C5278878 | ESD Suppressor Diode TVS Bi-Dir 24V 42Vc Automotive 3-Pin SC-70 T/R
DZ2,DZ3 | D_SOD-323 | 2 | MM3Z3V3ST | C182011 | SOD-323 Zener diode, 3.3V, 300mW, Alternate KiCAD Library
J1,J3,J4,J5 | JST_GH_BM04B-GHS-TBT_1x04-1MP_P1.25mm_Vertical | 4 | Conn_01x04_MountingPin | C161692 | Generic connectable mounting pin connector, single row, 01x04, script generated (kicad-library-utils/schlib/autogen/connector/)
J6 | JST_GH_BM07B-GHS-TBT_1x07-1MP_P1.25mm_Vertical | 1 | Conn_01x07_MountingPin | C378970 | Generic connectable mounting pin connector, single row, 01x07, script generated (kicad-library-utils/schlib/autogen/connector/)
J10,J11 | JST_GH_BM02B-GHS-TBT_1x02-1MP_P1.25mm_Vertical | 2 | Conn_01x02_MountingPin | C161690 | Generic connectable mounting pin connector, single row, 01x02, script generated (kicad-library-utils/schlib/autogen/connector/)
L2 | L_Changjiang_FXL0530 | 1 | 10uH 125mΩ 3.2A | C177248 | 10uH 125mΩ 3.2A 0530 Power Inductors ROHS
LED1,LED3,LED4 | 0603 | 3 | LED_0603_Amber | C2287 | Amber SMD LED, 0603, Alternate KiCad Library
Q3,Q4,Q5,Q6,Q7,Q8 | IFX-PG-TDSON-8-36-V | 6 | ISC030N10NM6 | C3278643 | Insulated-Gate Field-Effect Transistor (IGFET), N-Channel, Enhancement, Body Diode, Pin 1 Source, 2 Source, 3 Source, 4 Gate, 5 Drain, 6 Drain, 7 Drain, 8 Drain, 8 Pins
R10,R72 | 0402 | 2 | 24.9k 1% | C25874 | 24.9k ±1% 1/16W 0402 Chip Resistor - Surface Mount ROHS
R11,R17,R18,R38,R40 | 0402 | 5 | 10k 1% | C25744 | 10k ±1% 1/16W 0402 Chip Resistor - Surface Mount ROHS
R12,R16,R19 | 0402 | 3 | 100k 1% | C25741 | 100k ±1% 1/16W 0402 Chip Resistor - Surface Mount ROHS
R13,R14,R15 | 0402 | 3 | 56R 1% | C25127 | 56R ±1% 1/16W 0402 Chip Resistor - Surface Mount ROHS
R20,R21,R25,R26,R30,R31,R58 | 0805 | 7 | 0R 1% 1/8W | C17477 | 0R ±1% 1/8W 0805 Chip Resistor - Surface Mount ROHS
R22,R27,R32 | 2512 | 3 | 3mΩ 3W 1% | C5375459 | 3mΩ ±1% 3W 2512 Chip Resistor - Surface Mount ROHS
R36,R39,R42,R44 | 0402 | 4 | 2k 1% | C4109 | 2k ±1% 1/16W 0402 Chip Resistor - Surface Mount ROHS
R37 | 0603 | 1 | 10k NTC | C124898 | 10k NTC Thermistor 0603 NTC Thermistors ROHS
R41,R62,R65,R66 | 0402 | 4 | 1k 1% | C11702 | 1k ±1% 1/16W 0402 Chip Resistor - Surface Mount ROHS
R45,R46 | 0805 | 2 | 60R4 1% | C228935 | 60R4 ±1% 1/8W 0805 Chip Resistor - Surface Mount ROHS
R47,R48,R49,R50,R51,R52,R53,R54 | 0402 | 8 | 100R 1% | C25076 | 100R ±1% 1/16W 0402 Chip Resistor - Surface Mount ROHS
R73 | 0402 | 1 | 12.4k 1% | C11692 | 12.4k ±1% 1/16W 0402 Chip Resistor - Surface Mount ROHS
SW1 | Slide_DPDT_SMD_7.2x3.5mm | 1 | SW_Push_DPDT | C2837066 | Momentary Switch, dual pole double throw
U1 | TSSOP14_OSM | 1 | AS5047P-ATSM | C962063
U3 | DDA0008J | 1 | LMR36520ADDAR | C2879422
U5 | LQFP-64_10x10mm_P0.5mm | 1 | STM32G431RBTx | C431633 | STMicroelectronics Arm Cortex-M4 MCU, 128KB flash, 32KB RAM, 170 MHz, 1.71-3.6V, 52 GPIO, LQFP64
U6 | RTA0040B | 1 | DRV8323SRTAR | C2150452
U7 | WDFN-6_2x2mm | 1 | TLV75733PDRV | C2868428 | 1A Low IQ Small Size Low Dropout Voltage Regulator, Fixed Output 3.3V, WSON6
U8 | D0008A-IPC_A | 1 | TCAN1044AVDRQ1 | C3234993
X1 | Crystal_SMD_3225-4Pin_3.2x2.5mm | 1 | SMD3225-4 | C9006 | SMD Quartz crystal, 4 terminals, 3.2mm x 2.5mm, Alternate KiCad Library

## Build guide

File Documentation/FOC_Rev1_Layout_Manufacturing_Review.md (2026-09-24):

# FOC Motor Controller Rev 1 — Layout & Manufacturing Review

**Reviewed from the fab package, not the schematic:** gerbers (6 layers), PTH/NPTH drill, IPC-356 netlist, BoM, and pick-and-place.
**Board is design-frozen and at fab.** Everything below is sorted by whether you can still act on it.

---

## 0. Headline

This is a good board. The layout does the things that actually matter for a 60 V inverter: both inner ground planes are solid and completely unbroken, the high-side FET drains have proper 4×4 via-in-pad fields, the stencil is windowpaned on every thermal pad, and power-in and phase-out share one board edge right next to the power stage.

More importantly, **the single biggest risk flagged in DDR-001 has been closed**: the encoder is back on the board, at (40.00, 40.00) — the exact geometric centre. That eliminates the unshielded SPI-over-moving-cable failure mode that the design record called "the most likely source of intermittent field failures in this design."

There is **one item that may still be actionable at the fab**, because it is an order option rather than a gerber change. It is in §1 and it is worth a phone call.

---

## 1. Still actionable — fab order options, not file changes

### 1.1 ⚠ Via-in-pad plugging on the high-side FET drains — URGENT

Each high-side FET (Q3, Q5, Q7) has **16 vias, 0.25 mm drill, inside its drain pad**. The top solder mask has a **single 4.41 × 3.73 mm opening** covering the whole pad, so those vias are open plated-through holes sitting in the middle of a solder joint.

```
Per high-side FET:   16 × Ø0.25 mm via, 0.55 mm pad
Drain pad:           4.41 × 3.73 mm = 16.4 mm², one mask opening
Total affected:      48 open vias in 3 solder pads
```

If the order was placed without **resin-plugged and copper-capped via-in-pad** (POFV), then during reflow solder wicks down all 48 barrels by capillary action. The consequences, in order of how much they hurt:

1. **Voiding under the thermal pad** — which destroys the exact thermal path the vias were placed to create. You lose the benefit and keep the cost.
2. **Solder balls on the bottom side**, under a board that mounts against a chassis face.
3. **Component tilt / open pins** on a 5×6 package as solder is depleted unevenly.

**Do this now:** check the order. If via-in-pad plugging was not selected, contact JLCPCB before the board enters plating. This is a process option, so it may be changeable without a new upload. If it has already gone past that point, plan on X-raying the first article at the FET pads before you power anything.

If it cannot be changed: the boards are still usable at the 10 A design point, but treat the thermal numbers as unverified and inspect the joints.

### 1.2 Confirm the copper weight

Every thermal and current-capacity number in DDR-001 assumes **2 oz outer copper**. Nothing in a gerber records copper weight — it is purely an order parameter, and 1 oz is the default.

At 1 oz, your phase conductors carry roughly half the current for the same temperature rise, and the low-side FET thermal path (§2.1) gets materially worse. Verify the order line item says 2 oz outer.

### 1.3 Confirm the stackup

Six layers, L2 and L5 as ground. What matters for the power stage is the **L1↔L2 dielectric thickness** — that spacing sets the return-path loop area for every switching edge on the top layer. JLCPCB's default 6-layer buildup is normally thin between L1 and L2, which is what you want, but it is worth confirming rather than assuming, since it is the one stackup parameter that directly affects the commutation loop.

### 1.4 Via geometry is at, not inside, the recommended minimum

You used 0.25 mm drill on a 0.55 mm pad — a **0.15 mm annular ring**. <cite index="5-1">JLCPCB advises an annular ring of at least 0.15 mm to mitigate drill breakout during fabrication</cite>, so you are exactly on the line rather than inside it. <cite index="1-1">Their capabilities page gives a preferred minimum via hole of 0.2 mm with the via diameter 0.15 mm larger</cite>.

Not a problem, but no margin for registration error on a 6-layer lamination. For Rev 2, 0.3 mm / 0.6 mm costs nothing and buys back the margin.

---

## 2. Findings you cannot change — manage these at bring-up

### 2.1 ⚠ The low-side FETs have no vertical thermal path

This is the most consequential layout finding.

```
Q3, Q5, Q7 (high-side):  16 × +VPROT via-in-pad each → inner-layer spreading
Q4, Q6, Q8 (low-side):    0 vias
Switch nodes OUT_A/B/C:   0 vias anywhere on the board
```

Keeping the switch nodes entirely on L1 is a **deliberate and defensible EMI choice** — no switching copper on inner layers, no via stubs on the noisiest nets. But it means the low-side devices dissipate only into top-layer copper, while the high-side devices get a via field into a plane.

Measured copper in each phase zone (L1, region x±7 mm, y 58.5–71.5):

```
Phase C zone: 140.6 mm² total copper
Phase B zone: 149.0 mm²
Phase A zone: 159.1 mm²
```

That total is shared between the +VPROT pour, the switch-node pour, and the phase-output run — so the low-side drain sees perhaps 80–100 mm², not the 600 mm² (6 cm²) the datasheet's 50 °C/W figure assumes, and not the ≥200 mm² per device DDR-001 §11.1 specified.

**Revised estimate for the low-side devices** (R_thJA ≈ 75 °C/W, estimated by scaling — verify on the bench):

| Phase current | P per FET | ΔT (75 °C/W) | T_j at 40 °C | DDR-001 claimed |
|---|---|---|---|---|
| 10 A (design) | 0.42 W | 32 °C | **72 °C** ✓ | 61 °C |
| 20 A (stress) | 1.44 W | 108 °C | **148 °C** | 112 °C |

**At the 10 A design point this is completely fine.** The 20 A stress claim in DDR-001 does not survive the as-built low-side thermal path — margin to the 175 °C limit drops from ~63 °C to ~27 °C, before you account for the shunt dissipating another 1.2 W right next to it.

**Action:** treat 10 A as the rated figure, and thermally characterise the **low-side** devices specifically at bring-up. Do not assume the high-side measurement represents the leg. Update DDR-001 §5 to record the asymmetry.

### 2.2 ⚠ Bulk capacitance dropped from 5 pieces to 3

```
BoM line: C34, C37, C39 — 3 × 100 µF / 100 V (C42371899)
DFD-001 froze:            5 pieces
```

C41 and C42 were reassigned to other components (1 µF and 2n2 respectively), so this is a real reduction, not a renumbering.

The earlier sizing work concluded piece count is set by **ripple-current capacity and can surface area**, not by capacitance, and that three pieces sits at roughly 96 % of the required ripple current — i.e. **overloaded**, on a 2000-hour part. Five was called the minimum defensible count.

Running an aluminium-polymer capacitor at or above its ripple rating does not fail immediately; it shortens life through self-heating. So this is a longevity issue, not a bring-up issue.

**Action:** measure actual ripple current per capacitor at your real operating point before committing to a production run. The 7.8 A figure was derived at 10 A/phase with assumptions about modulation and duty; the real number may be lower. If it holds, Rev 2 goes back to five, or to a lower-ESR part.

### 2.3 The board NTC sits at the coolest point on the board

```
R37 (10 k NTC):  (39.00, 40.25)  — board centre
FET array:       y ≈ 62.5        — 22 mm away
U1 (AS5047P):    (40.00, 40.00)  — directly underneath
```

The sheet-11 note in the annotation guide asked for the NTC to be "in the thermally interesting zone — near the FET array or the hottest expected region — NOT in a cool corner where it will read low and give false confidence." It ended up at board centre, which is about as far from the power stage as it is possible to get on this board.

It will also partly read the encoder IC's self-heating, which is a constant offset unrelated to inverter load.

**Action:** this is a calibration problem, not a defect. Characterise the offset between R37 and an actual FET-case thermocouple across load, and put that delta into the firmware's over-temperature threshold. Write the measured offset into the design record so the number doesn't get lost.

### 2.4 Encoder at board centre — verify angle error against phase current

Putting the AS5047P at the exact board centre is the right call and closes the biggest risk in DDR-001. There is one second-order effect worth measuring.

The phase conductors carry up to 10 A RMS and run ~22 mm from the sensor die. A straight conductor produces:

```
B = µ₀·I / (2πr) = (4π×10⁻⁷ × 10) / (2π × 0.022) ≈ 91 µT ≈ 0.9 gauss
```

Against a typical AS5047P working field of 300–700 gauss, that is roughly 0.15–0.3 % — an angle error on the order of 0.1–0.2°. Small, but it is **current-dependent and therefore torque-correlated**, which in an FOC loop shows up as torque ripple and a small efficiency loss rather than as random noise.

**Action:** at bring-up, log encoder angle against a known mechanical reference while sweeping Iq at fixed rotor position. If the error correlates with current, it is compensable in firmware with a simple current-proportional offset term. Cheap to check, annoying to diagnose later.

### 2.5 No fiducials on the top layer

Searched the top mask for isolated round openings 1.5–4 mm with no drill nearby: **zero found**. The bottom has four clustered openings that are DNP component pads, not fiducials.

Your finest pitch is 0.5 mm (DRV8323 WQFN-40 and STM32 LQFP64). JLCPCB will normally place their own fiducials on the panel rails, which is usually adequate at 0.5 mm pitch, so this is unlikely to cause a failure on this run. But local fiducials next to the two fine-pitch parts are standard practice and cost nothing.

**Rev 2:** three global fiducials plus locals on U5 and U6.

### 2.6 No reference designators on the silkscreen

The silkscreen carries **functional** labels — and does it well (see §3). What it does not carry is `R47`, `C25`, `U6`-style designators. That is fine for machine assembly, which uses the position file, but it makes hand rework and bench debugging harder: you cannot look at the physical board and identify a part without the fab drawing open beside you.

For a board you intend to open-source, where other people will hand-assemble and probe it, this matters more than usual.

**Rev 2:** designators on silk at 0.5–0.6 mm where space allows, at minimum on the ICs, connectors, and anything you expect to swap.

### 2.7 Verify the E-stop polarity is fail-safe

The e-stop input is well built. `DRV_ENABLE` reaches J11 at (70.50, 19.00) through a proper conditioning network:

```
R41 (1 k)    series limiting at (65.00, 19.50)
C42 (2n2)    filter at (66.50, 19.00)
DZ3          clamp at (66.00, 25.50)
R19 (100 k)  pulldown near the driver at (28.75, 29.75)
```

Series resistance also means the external switch and the MCU GPIO cannot fight each other destructively if both drive the net — which was the failure mode I would otherwise have flagged.

**The one thing to confirm on the bench:** with the e-stop cable **unplugged**, does the driver end up disabled? The 100 k pulldown suggests yes (open = disabled = fail-safe), which is the correct behaviour. But the project record notes a polarity flip made at some point for bench convenience, which would make a cut cable read as "run". Verify empirically, and write the answer into DDR-001 D-19 — this is a safety property, not a detail.

### 2.8 Small things

- **CAN termination:** R45/R46 (60R4) are fitted but J2 (the select header) is DNP, so boards ship unterminated. Correct default for a 6-node bus. Just make sure you can actually enable it on the two end nodes — solder a header or bridge the pads.
- **SWD header J7 is DNP.** You will need to hand-solder one for bring-up. The pin-by-pin silkscreen makes this painless.
- **LED3 and LED4 are both silkscreened "MCU".** Cosmetic, but give them distinct labels in Rev 2.
- **`DZ1` is absent from the BoM.** If that was the bus-sense clamp, the VBAT_SENSE node now has no zener backstop. At 65 V bus the divider (24.9k + 12.4k / 2k) outputs ~3.31 V against a 3.3 V rail — the MCU's internal clamp will handle the microamps through a ~1.9 kΩ source, but confirm this was intentional.
- **Designator gaps** (LED2, and several R/C numbers) are from parts removed during the redesign. Harmless, but a reviewer will ask.

---

## 3. What's notably good

Worth recording, because a review that only lists problems gives a false impression.

**L2 and L5 are perfect.** Solid, unbroken ground planes across the entire board with nothing but via antipads — no splits, no slots, no routing. Under the power stage specifically, which is where DDR-001 §11.2 said it mattered most. This is the single most important thing to get right on a board like this and it is right.

**High-side via-in-pad is generous.** 16 vias per drain against the ≥9 specified. Assuming §1.1 gets resolved, the high-side thermal path is better than the design record assumed.

**Every thermal pad is windowpaned.** FET drains: 15 apertures, none larger than 3 mm². DRV8323 and STM32 pads likewise. This is the difference between a flat joint and a floating part, and it is easy to forget.

**The encoder decision was reversed correctly.** On-board, dead centre, coaxial. This closes the highest-rated risk in the entire design record, and the AUX connector (J6, 7-pin GH with 100 R series damping) is retained so an external encoder is still an option.

**Single-point chassis bond, implemented exactly as intended.** Four mounting holes each have a 0 Ω and a 1 nF/1 kV footprint. In the BoM: only **R58** is populated; R56, R57, R59 are DNP; all four capacitors fitted. One DC bond defines chassis potential, three HF-only couplings, no ground loop through the harness. This was the ambiguity flagged in the sheet-15 annotation and it was resolved the right way.

**Package downsize.** ISC030N10NM6 in PG-TDSON-8 (5×6 mm) rather than TOLL. DDR-001 D-06 flagged six TOLL packages as ~700 mm² of board bought for a stage dissipating under a watt — "margin that costs the primary system constraint." That got fixed. Board came in at **70.1 × 70.1 mm**, inside the 80 × 80 ceiling.

**Slew-control insurance is in place.** The gate-source RC networks (R23/R24/R28/R29/R33/R34 + C35/C36/C45/C46/C56/C57) are all **DNP with footprints reserved**. So you ship with pure IDRIVE control and can add damping after you see real waveforms, without a respin. That is precisely the recommendation from the annotation guide.

> **This also corrects a concern I raised earlier.** In the sheet annotations I calculated that the 2n2 gate-source caps would add 22 nC per device to the charge-pump budget, cutting margin to 1.35×. As built they are unpopulated, so the budget is back to the DDR-001 figure: **6 × 55 nC × 40 kHz = 13.2 mA against 25 mA, 1.9× margin.** If you later populate those caps to tame ringing, the budget tightens and you should re-check it at your final f_sw.

**Silkscreen is genuinely well done.** Title block populated (board name, Rev 01, date, your name), phase A/B/C labelled at the terminals, bulk cap polarity marked, power +/− marked, and the SWD header labelled pin-by-pin (3V3 / NRST / SWCLK / SWDIO / GND). Every connector named by function: I2C, UART, CAN ×2, MOTOR TEMP, ESTOP, AS5047 (AUX), 10k NTC. Someone picking this board up cold can find their way around it. This is the part of the schematic package that was weakest at review time and it is now the strongest part of the physical board.

**38 test points.** Good DFT coverage for a board this size.

**Power topology is clean.** Power in at (54, 71) and (63, 71), phases out at (18.5, 71), (30.0, 71), (41.5, 71) — all on the top edge, immediately adjacent to the FET row at y ≈ 62.5, with the bulk bank at x = 57–68 in between. Short, wide, and no power current crossing the signal side of the board.

**On bulk capacitor distance:** C34 and C37 sit 20–45 mm from the phase-C half-bridge, which looks alarming until you check the frequency. At 40 kHz, 40 nH of interconnect is about 10 mΩ of reactance against ~35 mΩ of capacitor ESR — so it barely affects ripple sharing. The high-frequency commutation loop is closed by the nine 4.7 µF MLCCs at y = 56.25, which are 6 mm from the FETs. **The placement is correct and the layout gets this right**; I am recording it because it is the kind of thing that gets "fixed" in a later revision by someone who didn't check the numbers.

---

## 4. Rev 2 list

Ordered by value.

| # | Change | Why |
|---|---|---|
| 1 | Thermal vias in the low-side drain pads, or a bottom-side switch-node pour | §2.1 — the only finding with a real performance consequence |
| 2 | Move R37 (NTC) into the FET zone, or add a second NTC there | §2.3 — you cannot control a temperature you measure 22 mm away |
| 3 | Bulk back to 5 pieces, or a higher-ripple part | §2.2 — capacitor longevity |
| 4 | Fiducials: 3 global + locals on U5/U6 | §2.5 |
| 5 | Reference designators on silkscreen | §2.6 — matters for an open-source board |
| 6 | Vias to 0.3 mm / 0.6 mm | §1.4 — free registration margin |
| 7 | Resolve DDR-001 blockers B1 (TVS clamp above two 65 V abs-max ICs) and B3 (generator mode) | Carried forward, still open |
| 8 | Distinct LED labels; close the designator gaps | Cosmetic |

---

## 5. Updates to make in DDR-001

The design record is now behind the hardware. To keep it useful:

- **D-21 (off-board encoder):** status changes from CONFIRMED-but-flagged to **REVERSED**. Record why, and record the new second-order risk (§2.4) in its place. This is the most interesting entry in the whole document now — a flagged risk that got designed out.
- **D-06 (MOSFET package):** the TOLL over-provisioning trade-off was resolved in favour of the 5×6 package. Mark it closed and note the resulting board size.
- **§5 thermal tables:** add the high-side / low-side asymmetry. The single "P per FET → T_j" table no longer describes the board.
- **D-08 (bulk capacitance):** frozen at 5, built at 3. Record the deviation and the ripple-current consequence rather than silently editing the number.
- **D-19 (safety):** an e-stop input now exists in hardware. Update, and add the measured fail-safe polarity once verified.
- **D-31 / §14 B1:** the buck is LMR36520 at **65 V** absolute maximum, not the 80 V part the document names. The TVS clamps at 82.4 V, so it now exceeds the absolute maximum of two ICs rather than one. B1 got worse, not better.
- **§13 Corrections:** add an entry for the charge-pump budget — the 2n2 gate-source cap concern was raised, then rendered moot by those caps shipping DNP. That is the same pattern as the 1N4148 gate diode: a concern that evaporated when its premise changed.

---

## 6. Bring-up sequence given the above

1. **Inspect before powering.** X-ray or cross-section one board at a high-side FET drain to check for wicking voids (§1.1). Verify copper weight against the order.
2. **Power the logic only**, driver disabled. Confirm rails, confirm the e-stop polarity is fail-safe with the cable unplugged (§2.7).
3. **Encoder characterisation, no motor current.** Baseline angle accuracy.
4. **Low current, motor spinning.** Sweep Iq at fixed rotor position and check for current-correlated angle error (§2.4).
5. **Thermal run at 10 A.** Thermocouple on a **low-side** FET case and on R37 simultaneously. Record the delta — that is your NTC calibration constant (§2.1, §2.3).
6. **Ripple current on one bulk capacitor** with a current probe, at the real operating point (§2.2).
7. Only then push toward 20 A, and stop at whatever the low-side thermal measurement says rather than at the number in the design document.

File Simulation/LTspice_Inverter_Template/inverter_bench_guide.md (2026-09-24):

# Half-Bridge Simulation Bench — User Guide

**File:** `LTspice_Inverter_Template/inverter_gate_motor_template.asc`

This bench answers two questions and deliberately nothing else:

1. **Will the inverter survive being switched at 40 kHz?** (voltage overshoot vs. the 100 V FET rating, parasitic turn-on of the off device, snubber dissipation)
2. **What should the snubber actually be?** (measured from the real ring, not guessed)

It does *not* do FOC, SVPWM, or closed-loop control. That was the right call to cut — you do not need a modulator to answer either question. Switching stress is a *per-edge* phenomenon: every edge in an SVPWM waveform is the same edge you can study one at a time, and studying it one at a time is how the industry actually does it.

---

## 1. What you are looking at

The schematic reads left to right, following the power:

```
V1 ──R1── C1/R2 ──L1── C2/L2 ──┬── M1 (high side)
battery   bulk    loop   local  │    └─L3─┐
          cap      L    ceramic │         ├── PH ──L5──R3── back to bus
                                │    ┌────┘         (load)
                                └── M2 (low side)  ── Rsn/Csn snubber
                                     └─L4─ GND
```

| Part | What it represents |
|---|---|
| `V1`, `R1` | 12S pack and its wiring resistance |
| `C1`, `R2` | your C34/C37/C39 electrolytic bank and its ESR |
| `L1` | **commutation loop stray inductance** — the single most important parasitic in this whole file |
| `C2`, `L2` | the local HF ceramic at the bridge, and its ESL |
| `M1`, `M2` | the two FETs, as a fitted VDMOS model |
| `L3`, `L4` | package/source inductance |
| `Rsn`, `Csn` | the snubber you are sizing (your R13/R14/R15 + C25/C26/C27) |
| `L5`, `R3` | motor phase load |
| `V2`/`V3` + R/D networks | the DRV8323 gate drive, with separate source and sink paths |

Two things worth internalising before you run anything:

**`L1` causes the ringing, not the FET.** The overshoot you are about to snub is energy stored in loop inductance that has nowhere to go when current stops abruptly. A snubber dissipates that energy. Shrinking the loop *prevents* it. Snubbing is always the second-best fix — if the simulation says you need a big lossy snubber, the real answer is usually layout.

**The gate drive has asymmetric paths on purpose.** `Rsrc_G` (turn-on) and `Rsnk_G` (turn-off) are derived from the DRV8323's IDRIVE source/sink settings, which are genuinely different — sink is roughly 2× source at a given code. Turn-*off* speed is what sets your overshoot, so that asymmetry matters.

---

## 2. The one knob

Near the top of the left text column:

```
.param TEST=1
```

- `TEST=1` → double-pulse test (snubber sizing, EMC)
- `TEST=2` → continuous 40 kHz (survival check)

Everything else — pulse timing, simulation length, timestep, load resistance, whether the high side is driven — derives from that one number through `if()` expressions. Change nothing else to switch tests.

**To run:** open the `.asc` in LTspice, hit the running-man icon (or Simulate → Run). To see the measurement results: **View → SPICE Error Log**.

**To plot a signal:** click on a wire for its voltage, or on a component body for its current. To plot a *differential* voltage (like V(PH,sL)), click on one node and drag to the other.

---

## 3. TEST 1 — Double-pulse test

### Why this test exists

40 kHz is 40,000 switching edges per second. Looking at all of them at once tells you nothing. The double-pulse test isolates exactly one turn-off and one turn-on so you can see the transient properly, with a 100 ps timestep that would be unaffordable over a long run.

It also creates the *worst-case* conditions on purpose: the turn-off happens at a known, controlled current, and the second turn-on happens into a freewheeling body diode (which is when reverse-recovery current adds to your peak).

### What happens when you run it

| Time | Event |
|---|---|
| 1 µs | Low-side FET turns on. Current ramps in `L5` at `VBUS/LLOAD` ≈ 3.4 A/µs |
| 6 µs | **Turn-off #1.** Current ≈ 17 A. *This is your snubber measurement.* |
| 6–8 µs | Current freewheels through M1's body diode (M1's gate is held at 0 V in this mode) |
| 8 µs | **Turn-on #2** into the conducting body diode → reverse recovery spike |
| 13 µs | Turn-off #2 |

### What to plot

Start with these four:

- **`V(PH,sL)`** — drain-source of the device under test. This is the waveform you are sizing the snubber against.
- **`Id(M2)`** — drain current. Look at the turn-on at 8 µs for the reverse-recovery spike.
- **`V(geL,sL)`** — gate-source of the DUT. You should see a clear Miller plateau around 4.6 V.
- **`V(geH,sH)`** — gate-source of the *off* device. **If this crosses ~2.8 V you have parasitic turn-on and a shoot-through path.** This is a genuine blow-up mechanism and it is worth checking every time you change gate drive settings.

Zoom hard into the 6 µs edge. That is where all the information is.

---

## 4. Sizing the snubber properly

Do not guess and iterate. There is a measurement procedure that gets you the right answer in three runs, because the ring frequency tells you what the parasitics actually are.

### Step 1 — measure the undamped ring

Set `CSNUB=1p` (effectively no snubber). Run `TEST=1`. Zoom into the turn-off edge of `V(PH,sL)`.

Put cursors on two adjacent ring peaks. Read Δt. Then **f₀ = 1/Δt**. Also note the peak voltage.

### Step 2 — add a known capacitor and re-measure

Set `CSNUB` to something that visibly slows the ring — try `4.7n` — and set `RSNUB=0.001` so it is a pure capacitor, not yet damped. Run again, measure the new ring frequency **f₁**.

### Step 3 — solve for the real parasitics

You now have two equations and two unknowns:

```
C_par = C_added / ( (f₀/f₁)² − 1 )

L_par = 1 / ( (2π·f₀)² · C_par )
```

`C_par` is the effective output capacitance of the node; `L_par` is the effective loop inductance. **These are the numbers you actually wanted** — and notice you just measured your own layout's parasitic inductance without a VNA.

### Step 4 — pick R and C

```
R_snub ≈ √( L_par / C_par )        (the characteristic impedance — this is what critically damps it)

C_snub ≈ 3 to 5 × C_par             (bigger = more damping, more loss)
```

### Step 5 — verify, then check what it costs you

Re-run with your new values. Confirm the overshoot is where you want it, then look at the dissipation:

```
P_snub ≈ C_snub · V_bus² · f_sw
```

The `Psnub` measurement in the error log gives you the simulated number to check that against.

### A result you should brace for

Run the numbers on the values currently on your board — 2.2 nF at 50.4 V and 40 kHz:

```
P = 2.2n × 50.4² × 40k ≈ 0.22 W per snubber
```

Your R13/R14/R15 are 0402 parts rated 1/16 W (62.5 mW). That is roughly **3.5× over rating**. Verify it yourself with `Psnub` in TEST=2 rather than taking my arithmetic on faith — but if it holds, this is a real Rev 2 item, and it is exactly the thing your earlier review flagged as unverifiable because the switching frequency was never stated on the schematic. Now it is verifiable.

Your options if it confirms: larger resistor package, smaller `CSNUB` (costs damping), lower `f_sw`, or a different damping strategy entirely (e.g. improving the loop so you need less snubber). Worth thinking through which of those you actually want before deciding.

---

## 5. TEST 2 — Continuous 40 kHz

### Why

TEST 1 tells you about one edge. TEST 2 tells you whether the thing runs — steady-state currents, whether the transients repeat identically or build on each other, and what the snubber and FETs dissipate over many cycles.

### What changes

Set `TEST=2`. Both FETs now switch complementary at 40 kHz, 50 % duty, with 200 ns dead time. `RLOAD` switches to 1.7 Ω, giving roughly 15 A of DC load current. Simulation runs 400 µs (16 switching cycles) at a 2 ns timestep.

**This run is slow** — expect minutes, not seconds. That is the price of resolving nanosecond edges over hundreds of microseconds, and it is why TEST 1 exists.

### What to check

- **`Vds_pct`** in the error log — peak drain-source as a percentage of the 100 V rating. Under 80 % is the usual comfort threshold. Remember your SMCJ51CA TVS clamps around 82 V under surge, so the bus itself can transiently sit higher than 50.4 V before switching overshoot is even added.
- **`Vgs_hs_offpk`** — must stay well below `VTO` (2.8 V). This is your shoot-through margin.
- **`Psnub`** — the thermal question from Section 4.
- **`Id_ls_pk`** — peak current including recovery spikes, against the FET's pulsed rating.
- Plot `V(PH,sL)` across several cycles and confirm every edge looks the same. If overshoot grows cycle-on-cycle, something is not settling.

Useful addition if you want device loss: add a directive

```
.meas TRAN Pm2 AVG Id(M2)*V(PH,sL)
```

which gives average dissipation in the low-side FET (conduction + switching together).

---

## 6. Swapping in a different MOSFET

Change the eleven `.param` lines in the left column. Here is where each comes from on a datasheet:

| Param | Source |
|---|---|
| `VTO` | Vgs(th), typical |
| `KP` | `2·Id / (V_plateau − Vto)²` using the gate-charge test conditions |
| `RDON` | RDS(on) at the Vgs you actually drive |
| `RG_INT` | internal gate resistance Rg |
| `CGS_M` | Ciss − Crss, at the datasheet's Vds test point |
| `CGDMAX` | fit to Qgd — start around 100× `CGDMIN` and adjust until the plateau length matches |
| `CGDMIN` | Crss at the datasheet Vds |
| `CJO` | `(Coss − Crss) · √(1 + Vds_test/0.8)` |
| `RB` | from the body diode forward drop at rated current |
| `TT` | from Qrr |
| `BVDSS` | V(BR)DSS |

The `CJO` formula is worth understanding rather than just applying: LTspice models the body-diode junction capacitance as `Cjo/√(1+V/0.8)`, so you are back-solving the zero-bias value from the datasheet's value at its test voltage. For the ISC030N10NM6 that gives `(900p−15p)·√(1+50/0.8) ≈ 7.0 n`, which is what is in the file.

**Sanity-check after swapping:** run TEST=1 and confirm the gate plateau in `V(geL,sL)` sits at the datasheet's plateau voltage and lasts roughly `Qgd/I_drive`. If it does, your capacitance fit is good enough to trust the switching waveforms.

---

## 7. Swapping the motor

`LLOAD` is currently a **placeholder** (15 µH). ODrive does not publish phase inductance or resistance for the M8325s anywhere — I checked their shop pages and the community threads. The authoritative numbers come from your own hardware: ODrive's motor calibration measures phase resistance and inductance directly and reports them. Use those.

For this bench, `LLOAD` only sets the di/dt during the double pulse and the ripple in TEST 2. It is not critical to get exactly right for snubber sizing (the ring is set by `L1` and the FET capacitance, not the load), but it matters for realistic current levels.

---

## 8. What this model will not tell you

Be clear-eyed about the boundaries:

- **The gate driver is idealised.** No propagation delay, no adaptive dead time (the real DRV8323 senses Vgs and adjusts), no ISTRONG 2 A pulldown, no 150k/480k hold-off resistors. Your real parasitic-turn-on margin is *better* than this model suggests, not worse — so treat a `Vgs_hs_offpk` pass here as necessary, not sufficient.
- **Stray inductances are lumped guesses.** `LLOOP=15n` is a plausible value for a decent layout, not a measurement. The Step 3 procedure above lets you *extract* the real one once you have hardware — and then this model becomes genuinely predictive.
- **The VDMOS model is fitted, not vendor-validated.** Relative comparisons (snubber A vs. snubber B, gate resistor 0 Ω vs. 2.2 Ω) are trustworthy. Absolute loss numbers are indicative only.
- **No thermal model.** Nothing here heats up, and RDS(on) roughly doubles at 125 °C.
- **One leg only.** The real board has three legs sharing one bulk cap. Bus ripple current and sag are worse than this file shows.

---

## 9. Further reading

You already have several of these in the project:

- `sicmos_snubber_circuit_design_ane.pdf` — snubber design procedure, same method as Section 4
- `Mosfet optimization slvaf66.pdf` (TI SLVAF66) — §3.1.2 is the source of the gate-drive topology used here
- `MOSFET literature sbaa698a.pdf` — switching loss mechanisms
- `infineonisc030n10nm6datasheeten 1.pdf` — every model parameter traces back here

Worth adding:

- TI **SLUA618** — *Fundamentals of MOSFET and IGBT Gate Driver Circuits*, the standard reference for Miller plateau and parasitic turn-on
- LTspice's own help page for **VDMOS** — documents every parameter in the `.model` line
- Infineon's application notes on **double-pulse testing** — for how this is done on real hardware, which you will want when you get to bring-up

---

## 10. Suggested order of work

1. Run TEST=1 as shipped. Look at the turn-off edge. Get a feel for what the ring looks like.
2. Do the Section 4 extraction properly. Write down your `L_par` and `C_par`.
3. Pick R and C from the formulas, re-run, confirm.
4. Check `Psnub` against the resistor rating. Decide what to do about it.
5. Run TEST=2 once as a survival check and to get steady-state dissipation.
6. Sweep `RG_EXT` (0 Ω → 2.2 Ω → 4.7 Ω) in TEST=1 and watch overshoot vs. switching loss trade off. This is the argument for whether your current 0 Ω gate resistors are the right call.
7. Set `LS_PKG=0.1n` and re-run to see what a proper Kelvin gate connection buys you.

Steps 6 and 7 are where this file earns its keep — both are decisions you will otherwise be making on intuition.

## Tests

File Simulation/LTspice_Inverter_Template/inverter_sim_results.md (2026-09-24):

# Half-Bridge Simulation — Results, Risks, and Recommendations

Leg A of the FoC Motor Controller, ISC030N10NM6 + DRV8323, 12S bus (50.4 V nom / 56 V max), 40 kHz.
All numbers below are simulated on the netlist traced from `MOSFETs.kicad_sch`, with both snubber positions DNP as built.

---

## Headline

**The inverter will not blow up on voltage.** Peak Vds is 55 V on a 100 V part — 45 % margin, at every drive setting tested.

**The snubbers are not needed and do not help.** Leave R23/R24/C35/C36 depopulated.

**The real risk is somewhere else entirely:** shoot-through margin at the dead-time boundary is **0.06 V** at the as-built IDRIVE setting. That is the finding that matters, and it has a fix that also saves 38 % of switching loss.

---

## 1. Model validation (do not skip this)

A fitted model that is wrong in the wrong direction would have produced a confident, useless answer. Three checks:

| Quantity | Datasheet | Model | Note |
|---|---|---|---|
| RDS(on) @ Vgs=10 V, Id=25 A | 2.6 mΩ typ | 2.63 mΩ | via `mtriode=4.3` |
| RDS(on) @ Id=50 A | 2.6 mΩ typ (3.0 max) | 2.67 mΩ | |
| Qg to Vgs=10 V | 55 nC | 53.5 nC | |
| Qgd | 9.1 nC | 9.1 nC | `Cgdmax` fitted 1.5n → **1.8n** |

A single-equation MOSFET model cannot match RDS(on) *and* the Miller plateau simultaneously — the square law under-predicts gm at high current. `Kp` is fitted to the 4.6 V plateau and `mtriode` then corrects the triode conductance independently. Without that split, conduction loss would have been 2.5× too high.

The `Cgdmax` correction matters most: at the original 1.5 nF the model carried 8.0 nC of Qgd and switched too slowly, which **understates** ringing. It is now calibrated.

**Two artefacts I had to discard, flagged here so you don't trust them if you see them:**
- `V(geh,sh)` showed ±25 V to ±100 V spikes that moved erratically (25.8 → 1.55 → 95.4 → 1.69) across a *smooth* parameter sweep while Vds varied smoothly. Inspection showed three samples sharing one timestamp with `dt = 0`, during a quiet interval before any switching. Solver residue. 6 samples in 100,239.
- My first ring metric (RMS of Vds−Vbus after the edge) reported every snubber as *worse* than bare. It was measuring the freewheel diode offset — PH sits at Vbus+Vf ≈ 51.2 V, not 50.4 V — rather than any oscillation.

---

## 2. Parasitic extraction

Two-point method: ring frequency bare, then with a known 4.7 nF across the low-side device.

```
f₀ = 90.4 MHz   (bare)
f₁ = 41.7 MHz   (+4.7 nF)

C_par = 1271 pF      L_par = 2.44 nH      Z₀ = √(L/C) = 1.39 Ω
```

**The extracted 2.44 nH is not the 15 nH commutation loop, and that is the interesting part.** The local 100 n 0603 at the bridge bypasses the bulk loop at 90 MHz, so the real HF ring loop is package source inductance (2 × 0.5 nH) + shunt inductance (1.5 nH) + ceramic ESL (0.8 nH) ≈ 3.3 nH. Measured 2.44 nH. Your local decoupling is doing its job — the bulk loop never participates.

C_par = 1271 pF is consistent with Coss = 885 pF at 50 V plus the opposite device and strays.

---

## 3. Double-pulse result (as built, snubbers DNP)

```
Turn-off at 17 A, 50.4 V bus:

  Peak Vds        54.83 V      (54.8 % of BVDSS — 45 V of margin)
  Overshoot        4.43 V
  Ring            89.7 MHz
  Ring amplitude   0.64 V → 0.26 V over two cycles
  Settled         ~40 ns
  Peak Id         32.8 A       (17 A load + body-diode reverse recovery)
```

The ring is already near-critically damped by the circuit's own resistance — RDS(on), the 3 mΩ shunt, bank ESR. There is under 1 V of oscillation to suppress.

---

## 4. Snubber sweep — 32 combinations, none of them help

R ∈ {0.68 … 10 Ω} × C ∈ {1, 2.2, 3.3, 4.7 nF}, low-side position:

| Config | Vds peak | Ring amplitude (1st → 3rd extremum) |
|---|---|---|
| **Bare (as built)** | 54.83 V | 0.64 → 0.26 V @ 89.7 MHz |
| R=3.9 C=2.2n (board values) | 54.72 V | 0.97 → 0.41 V @ 88.5 MHz |
| R=1.5 C=3.3n (nearest to theory) | 55.01 V | 0.46 → 0.70 V @ 19.8 MHz |

Peak Vds moves by at most 0.7 V across the entire grid. No combination reduces ring amplitude below bare. Larger C simply drags the resonance down toward 20 MHz without damping it further.

**If EMC testing later forces the issue**, the theoretically correct values from the extraction are **R ≈ 1.4 Ω** (not 3.9 Ω — the board value is overdamped relative to Z₀) and **C ≈ 3.8–6.4 nF** (not 2.2 nF — undersized at ~1.7× C_par rather than 3–5×). But populate them only against a measured EMC failure, because lowering the ring from 90 MHz to 20 MHz is not automatically an improvement — it depends which band you are failing.

### Correction to what I told you earlier

I previously estimated snubber dissipation as `P = C·V²·f ≈ 224 mW` and called it 1.8× over the 0805 1/8 W rating. **That was wrong.** Simulated: **80 mW**.

`C·V²·f` assumes a step transition. Here RC = 3.9 × 2.2n = 8.6 ns against a ~60 ns edge, so the cap tracks the node quasi-statically instead of being hard-switched. The correct form in this regime is `2C²V²R·f / t_transition` ≈ 64 mW, which matches. The C·V²·f figure is an upper bound that only applies when RC ≫ transition time.

So the snubbers would be thermally *fine* if populated. They are just pointless.

---

## 5. Continuous 40 kHz — thermal

At the **10 A rms design point**, no snubber:

| IDRIVE (src/snk) | Vds peak | P(M2) low side | P(M1) high side | P(shunt) |
|---|---|---|---|---|
| **0.33 / 0.66 A (as built)** | 54.8 V | 1.23 W | 0.19 W | 0.26 W |
| 0.57 / 1.14 A | 56.1 V | 0.92 W | 0.20 W | 0.26 W |
| 1.00 / 2.00 A | 57.3 V | 0.74 W | 0.20 W | 0.26 W |

Shunt dissipation 0.26 W against a 3 W 2512 — comfortable.

At 15.5 A rms the IDRIVE sensitivity becomes dramatic:

| IDRIVE | P per leg |
|---|---|
| 0.06 / 0.12 A | **16.9 W** |
| 0.12 / 0.24 A | 5.75 W |
| 0.19 / 0.38 A | 3.76 W |
| 0.33 / 0.66 A (as built) | 2.82 W |
| 0.57 / 1.14 A | 2.36 W |
| 1.00 / 2.00 A | 2.08 W |

**Switching loss dominates: 1.66 W of M2's 1.98 W at as-built settings.** If you ever configure IDRIVE near the bottom of the table by mistake, the leg dissipates 17 W and the board dies. Worth a firmware assertion on the SPI register value.

---

## 6. The actual risk: shoot-through margin

Measured at the instant the low-side FET turns on, with the high-side driver commanding off:

| IDRIVE | Vgs(HS) at LS turn-on | Peak Vgs(HS) during the edge | Headroom to Vth |
|---|---|---|---|
| **0.33 / 0.66 A (as built)** | 1.25 V | **2.74 V** | **0.06 V** |
| 1.00 / 2.00 A | 0.41 V | 2.17 V | 0.63 V |

Vth = **2.8 V typical**. The as-built configuration clears it by 60 millivolts.

That is not a real margin, for three compounding reasons:

1. **Datasheet Vgs(th) minimum is 2.3 V**, not 2.8 V. On a min-threshold part, 2.74 V is already *above* threshold.
2. **Vth has a negative tempco** (≈ −6 mV/°C). At 125 °C junction, typical Vth falls to roughly 2.2 V and minimum to ~1.7 V. The 2.74 V excursion is then well into conduction.
3. The 200 ns dead time is not enough for the gate to discharge. With Rsnk = 15.15 Ω and Ciss = 4 nF, τ = 61 ns, so after 200 ns the gate is still at 1.25 V — and the low-side turn-on edge then Miller-couples another 1.5 V on top.

**Mechanism:** this is dead-time inadequacy compounded by Miller coupling, not a layout problem.

### Important caveat in your favour

The model uses a **fixed** 200 ns dead time. The real DRV8323's TDRIVE state machine uses **adaptive, Vgs-sensed** dead time — it waits for the gate to actually fall before switching the other device. If that is enabled, hardware has materially more margin than this model shows. **Confirm it is enabled before acting on this.** The model identifies the mechanism and the sensitivity; it does not model the mitigation that may already be present.

---

## 7. Recommendations

**Do not populate the snubbers.** R23/R24/C35/C36 stay DNP. The ring is under 1 V and damps in 40 ns; no R/C combination tested improves it. The DNP decision was correct.

**Raise IDRIVE to 0.57/1.14 A or 1.00/2.00 A.** This is the one change worth making and it wins on both axes:
- Shoot-through headroom: 0.06 V → 0.63 V
- Switching loss: −25 % to −38 %
- Cost: 1.5–2.5 V more overshoot, against 45 V of margin

**Do not add external gate resistance.** My earlier guide suggested sweeping RG_EXT upward to reduce overshoot. Given this result that trade is backwards — slower turn-off directly erodes the shoot-through margin, and you have voltage margin to spare. The 0 Ω resistors that were flagged as a layout risk are, on this evidence, the right call. Keep the footprints for flexibility.

**Verify the DRV8323 TDRIVE adaptive dead-time configuration** before trusting the 200 ns figure either way. If adaptive dead time is off, turn it on; if it cannot be, raise the fixed dead time to ≥ 300 ns (≈5τ).

**Add a firmware guard on the IDRIVE SPI register.** A mis-write to a low code costs 17 W per leg. Read the register back after configuration and refuse to enable TIM1 if it does not match.

**At bring-up, measure Vgs on the off device directly.** This is the one prediction here most worth confirming on hardware, because it is where the model is both least certain and most consequential. A differential probe across GHx–SHx during a low-side turn-on edge settles it.

---

## 8. What this does not cover

- No thermal feedback. RDS(on) roughly doubles at 125 °C; conduction loss above is a cold-board number. Switching loss dominates, so the totals move less than you'd fear.
- `LLOAD = 15 µH` is still a placeholder — replace with odrivetool calibration output. It sets di/dt and ripple, not the ring.
- One leg. Three legs share the bulk bank; bus ripple is worse than modelled.
- Stray inductances are estimates, but note the extraction in §2 is self-consistent and can be re-run against hardware to get the real numbers.
- Gate driver is idealised apart from IDRIVE source/sink impedance and the IHOLD path.

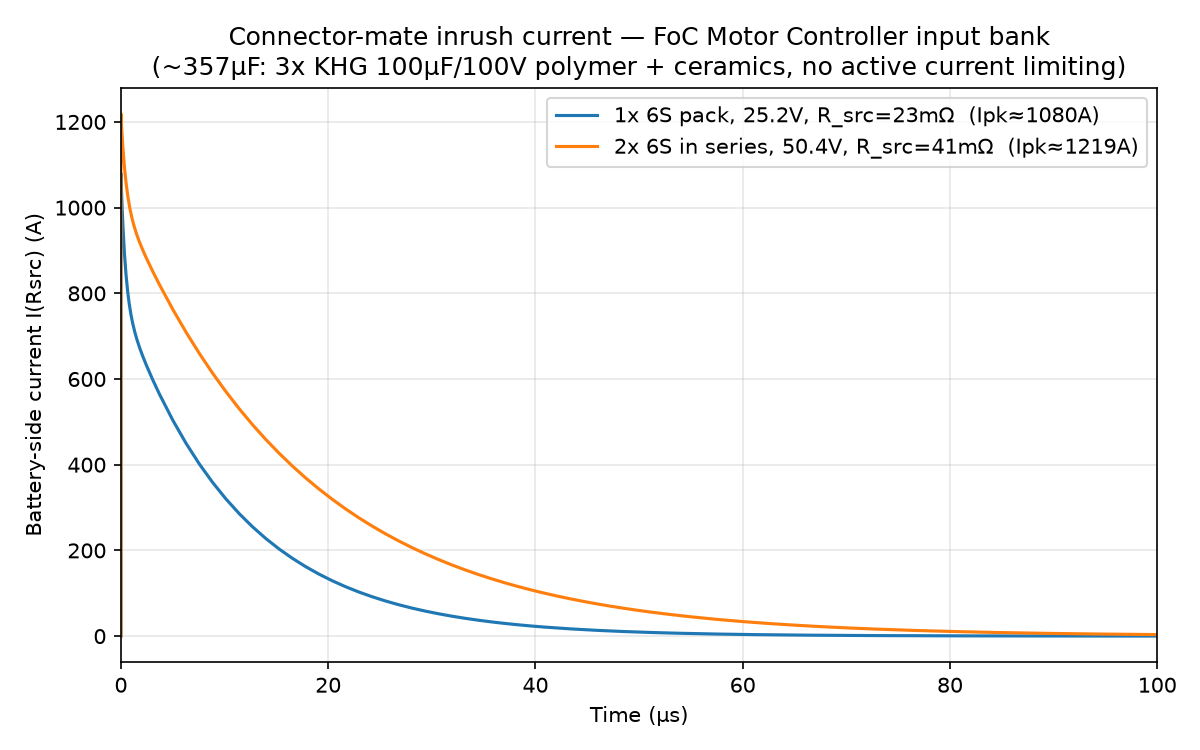
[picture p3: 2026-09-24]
Simulation/LTspice_Inrush_Test/inrush_current_both_scenarios.png

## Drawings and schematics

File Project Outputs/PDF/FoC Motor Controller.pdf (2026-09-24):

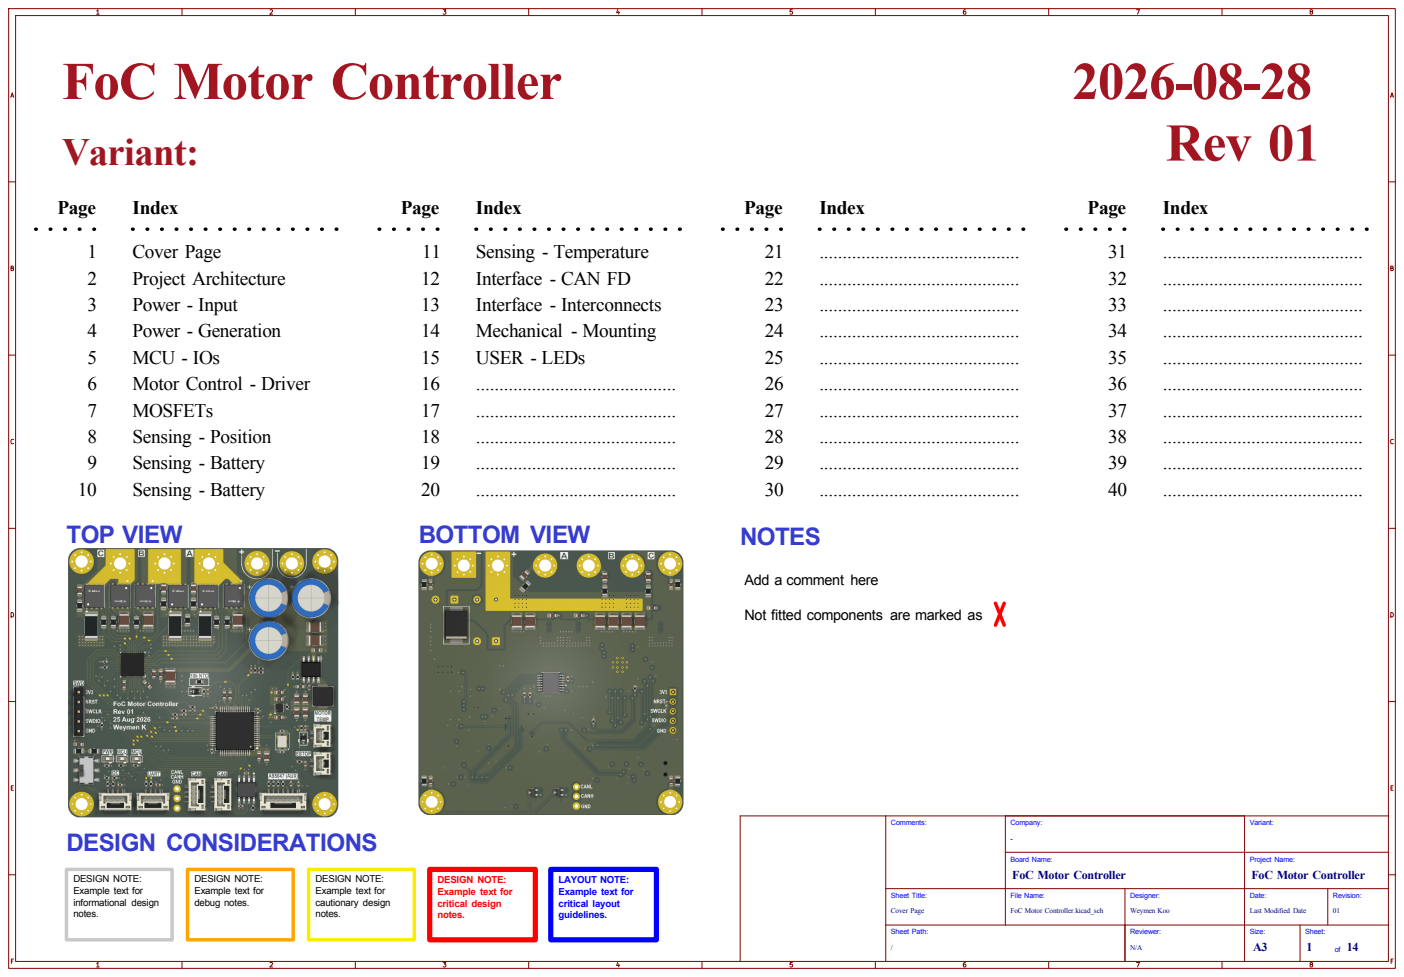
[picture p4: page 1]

Not fitted components are marked as

/Sheet Path: Cover Page Comments: Project Architecture

Revision: 01 Date: Project Name: Last Modified Date Reviewer: N/A

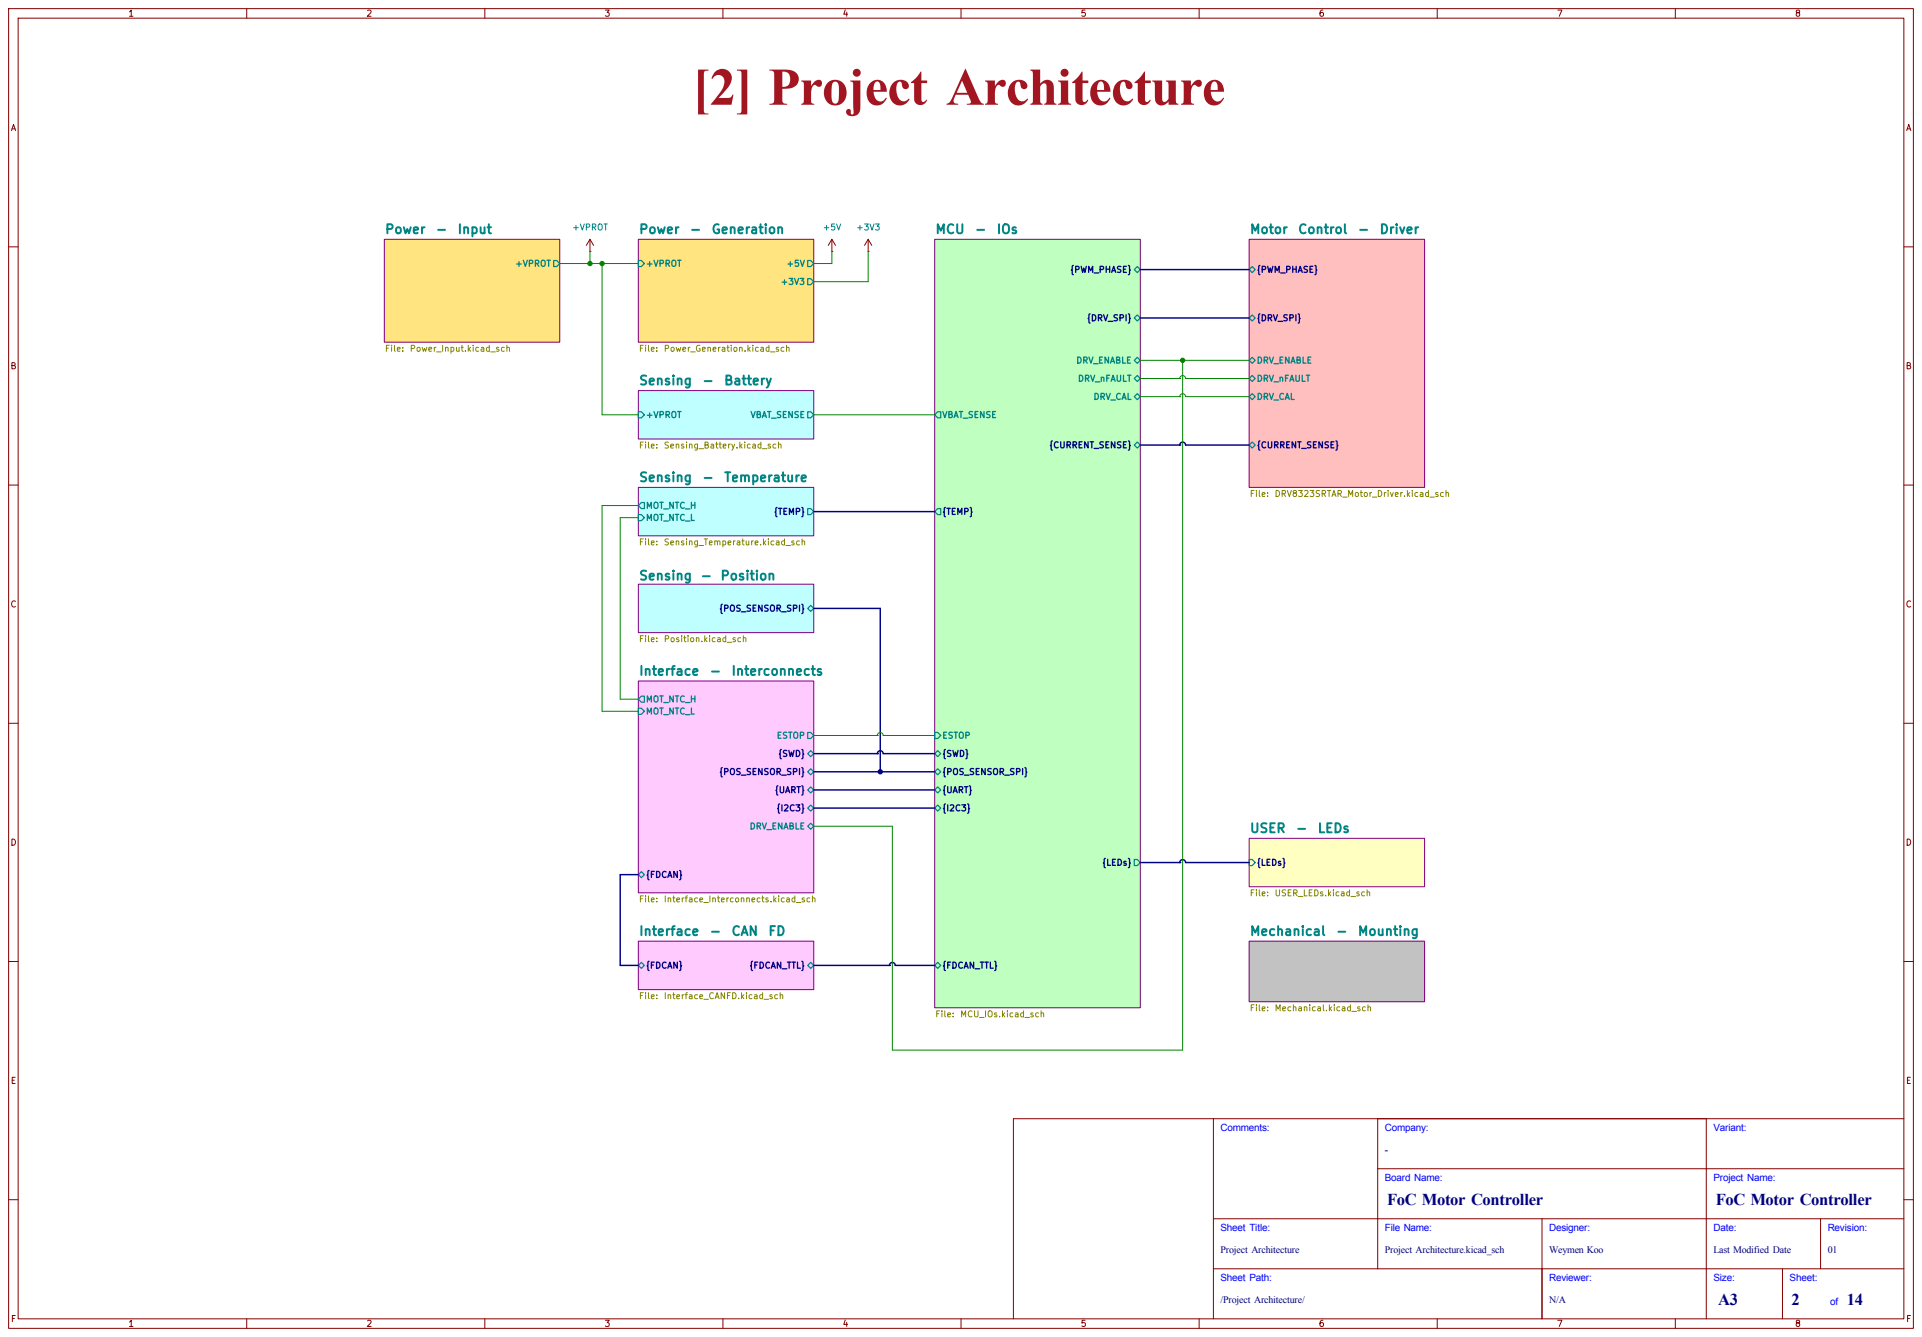
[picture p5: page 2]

+VPROT Power - Input File: Power_Input.kicad_sch

File: Mechanical.kicad_sch
/Project Architecture/ Sheet Path: Project Architecture Comments:

Revision: 01 Date: Project Name: Last Modified Date Reviewer: N/A

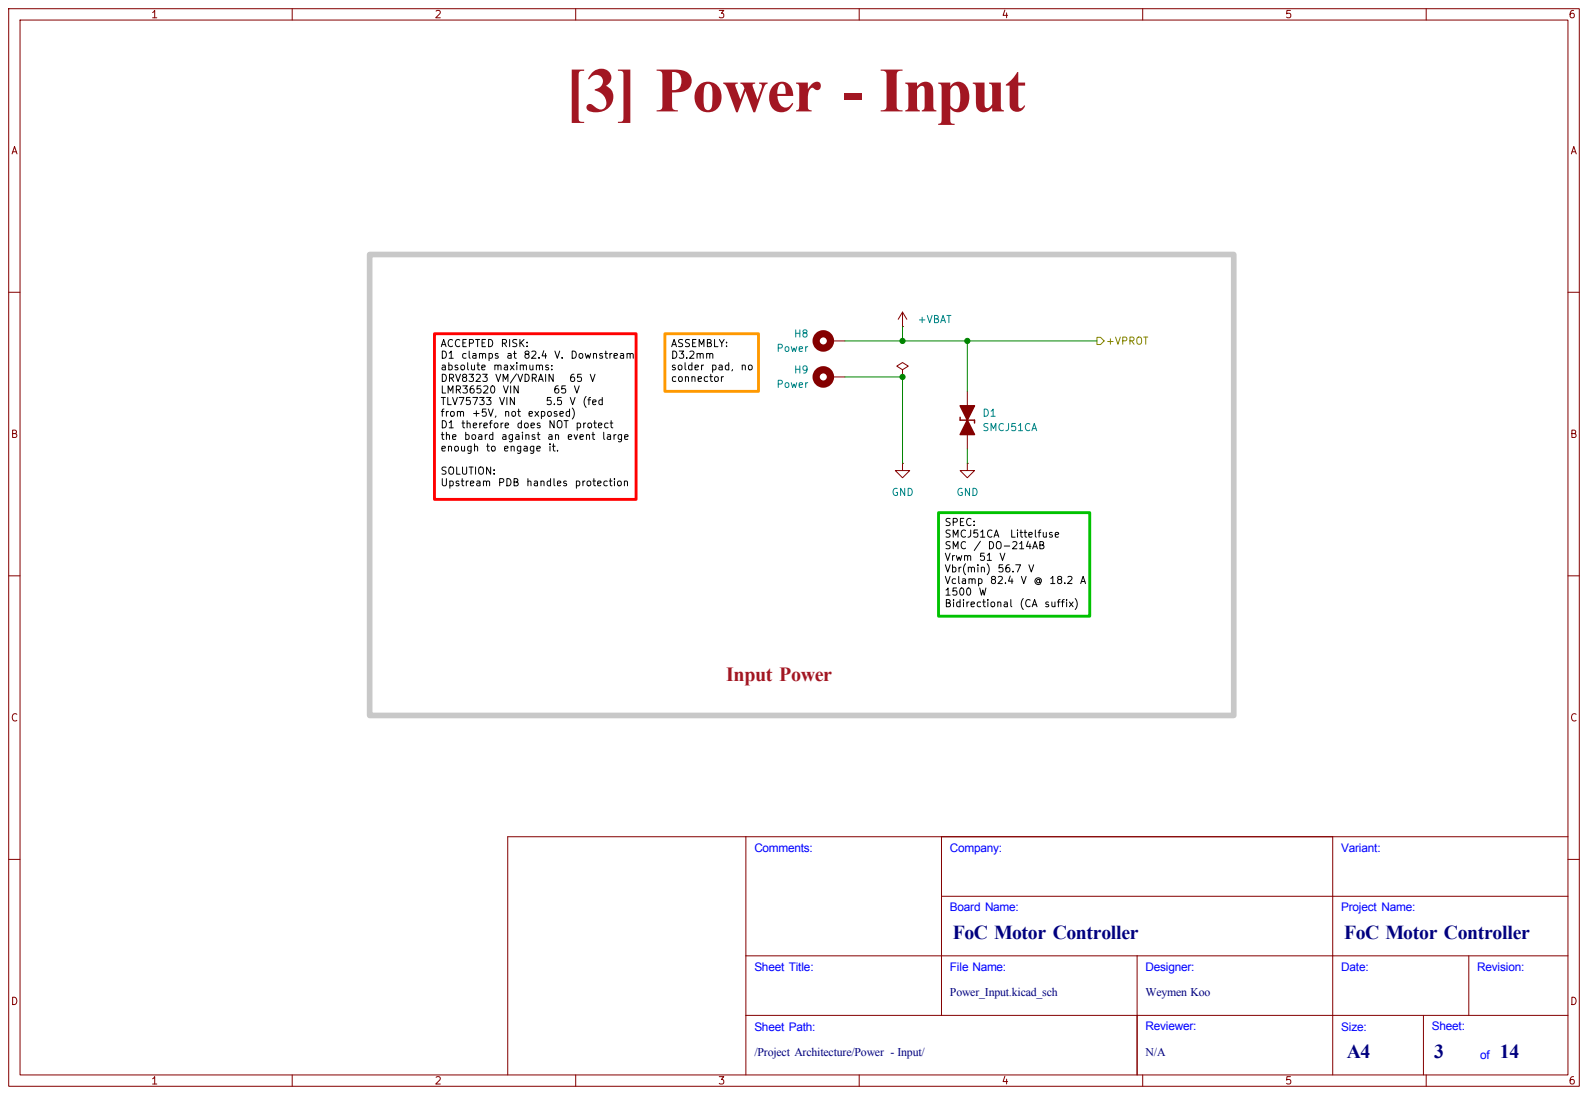
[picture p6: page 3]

from +5V, not exposed) D1 therefore does NOT protect

the board against an event large
enough to engage it. SOLUTION: Upstream PDB handles protection

SPEC: SMCJ51CA Littelfuse SMC / DO-214AB

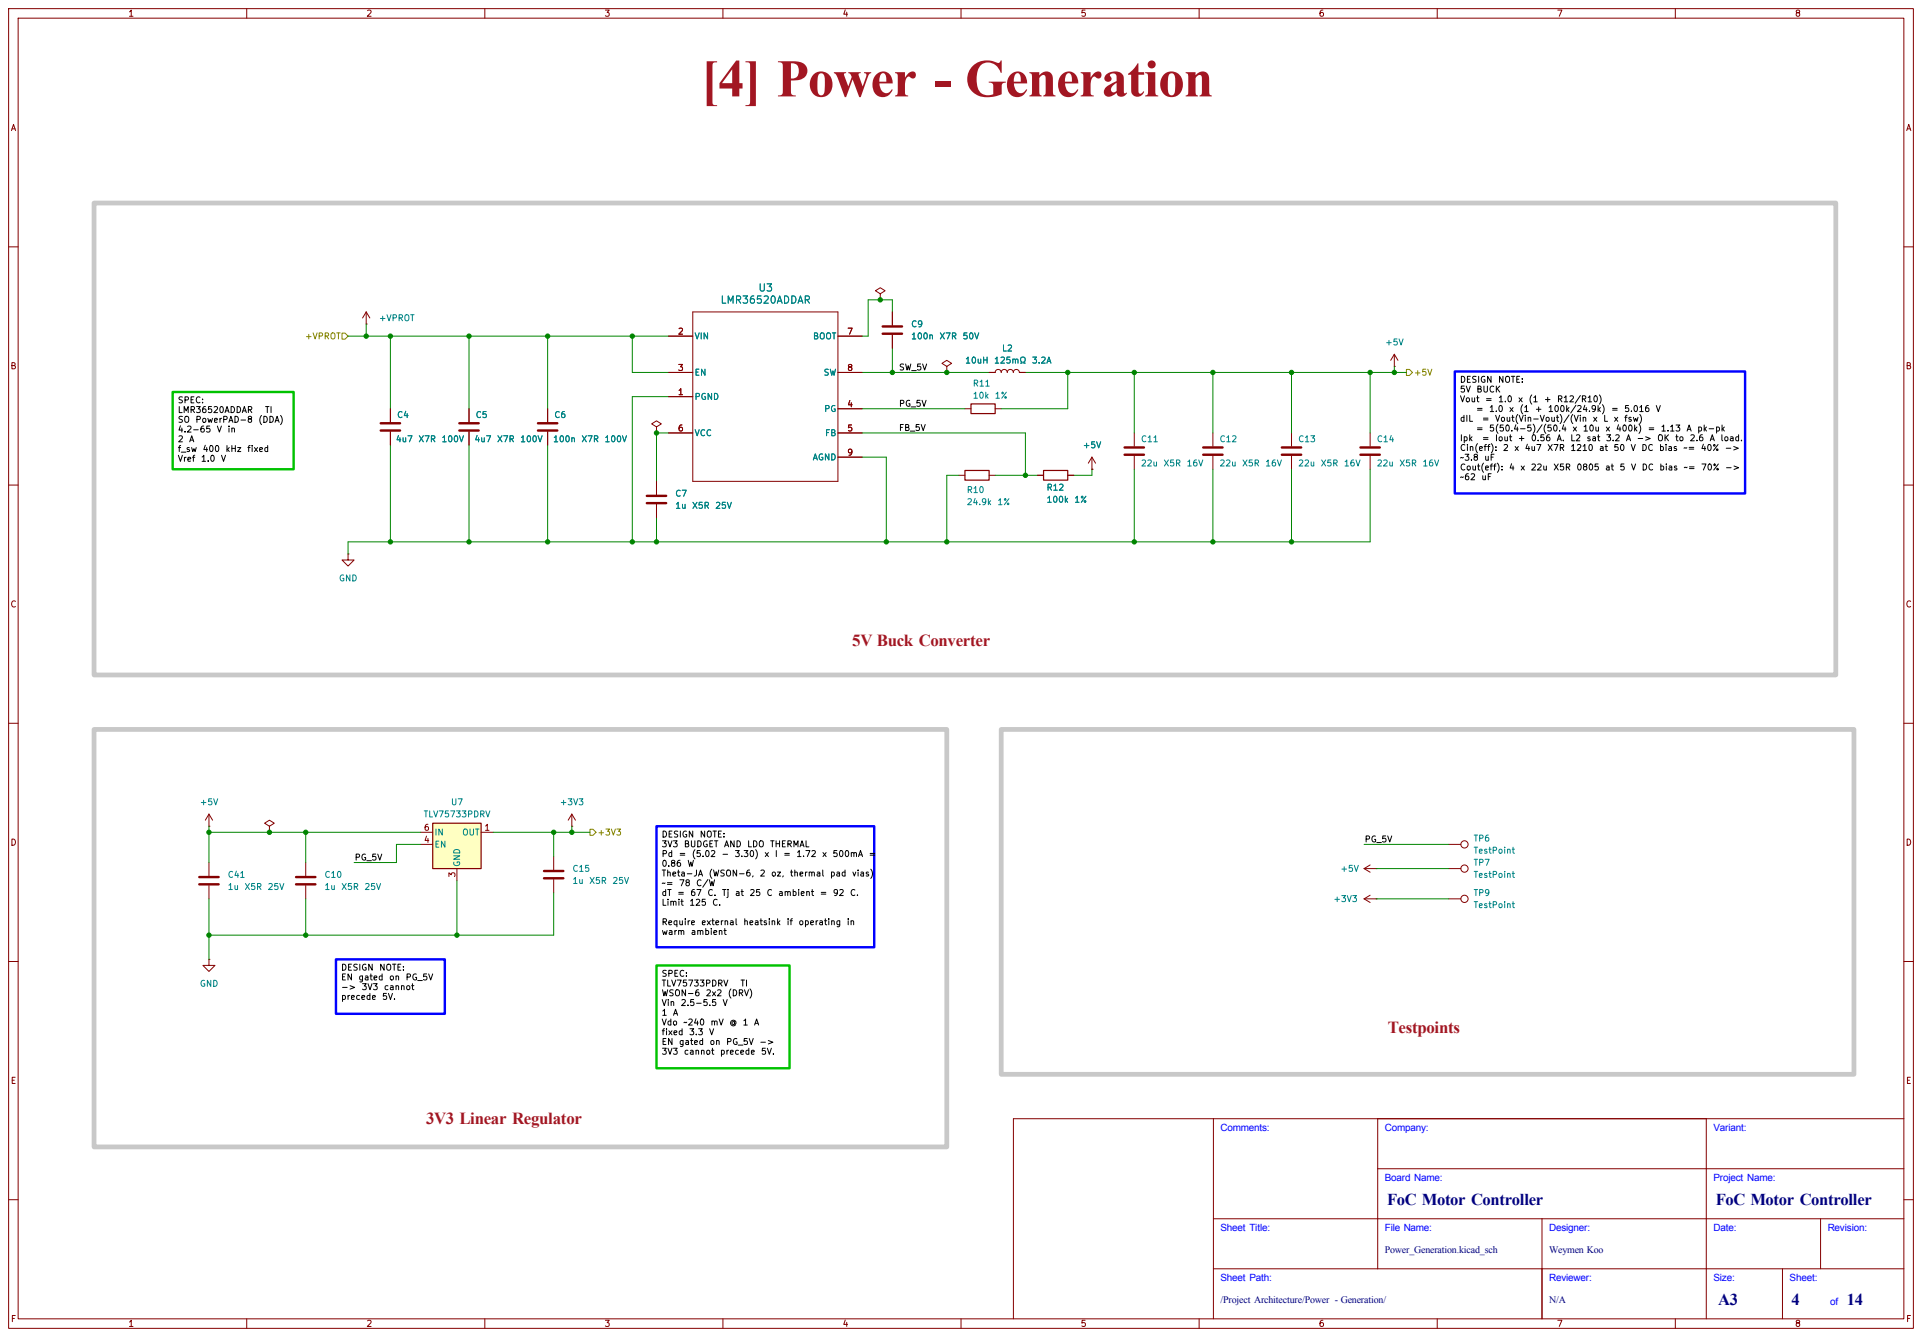
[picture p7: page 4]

Vout = 1.0 x (1 + R12/R10) = 1.0 x (1 + 100k/24.9k) = 5.016 V dIL = Vout(Vin-Vout)/(Vin x L x fsw) = 5(50.4-5)/(50.4 x 10u x 400k) = 1.13 A pk-pk

Ipk = Iout + 0.56 A. L2 sat 3.2 A -> OK to 2.6 A load. Cin(eff): 2 x 4u7 X7R 1210 at 50 V DC bias ~= 40% ->

~3.8 uF Cout(eff): 4 x 22u X5R 0805 at 5 V DC bias ~= 70% ->

DESIGN NOTE: 3V3 BUDGET AND LDO THERMAL Pd = (5.02 - 3.30) x I = 1.72 x 500mA =

Theta-JA (WSON-6, 2 oz, thermal pad vias) ~= 78 C/W

DESIGN NOTE: EN gated on PG_5V -> 3V3 cannot precede 5V.

Vdo ~240 mV @ 1 A
fixed 3.3 V EN gated on PG_5V ->

/Project Architecture/Power - Generation/ Sheet Path: Comments:

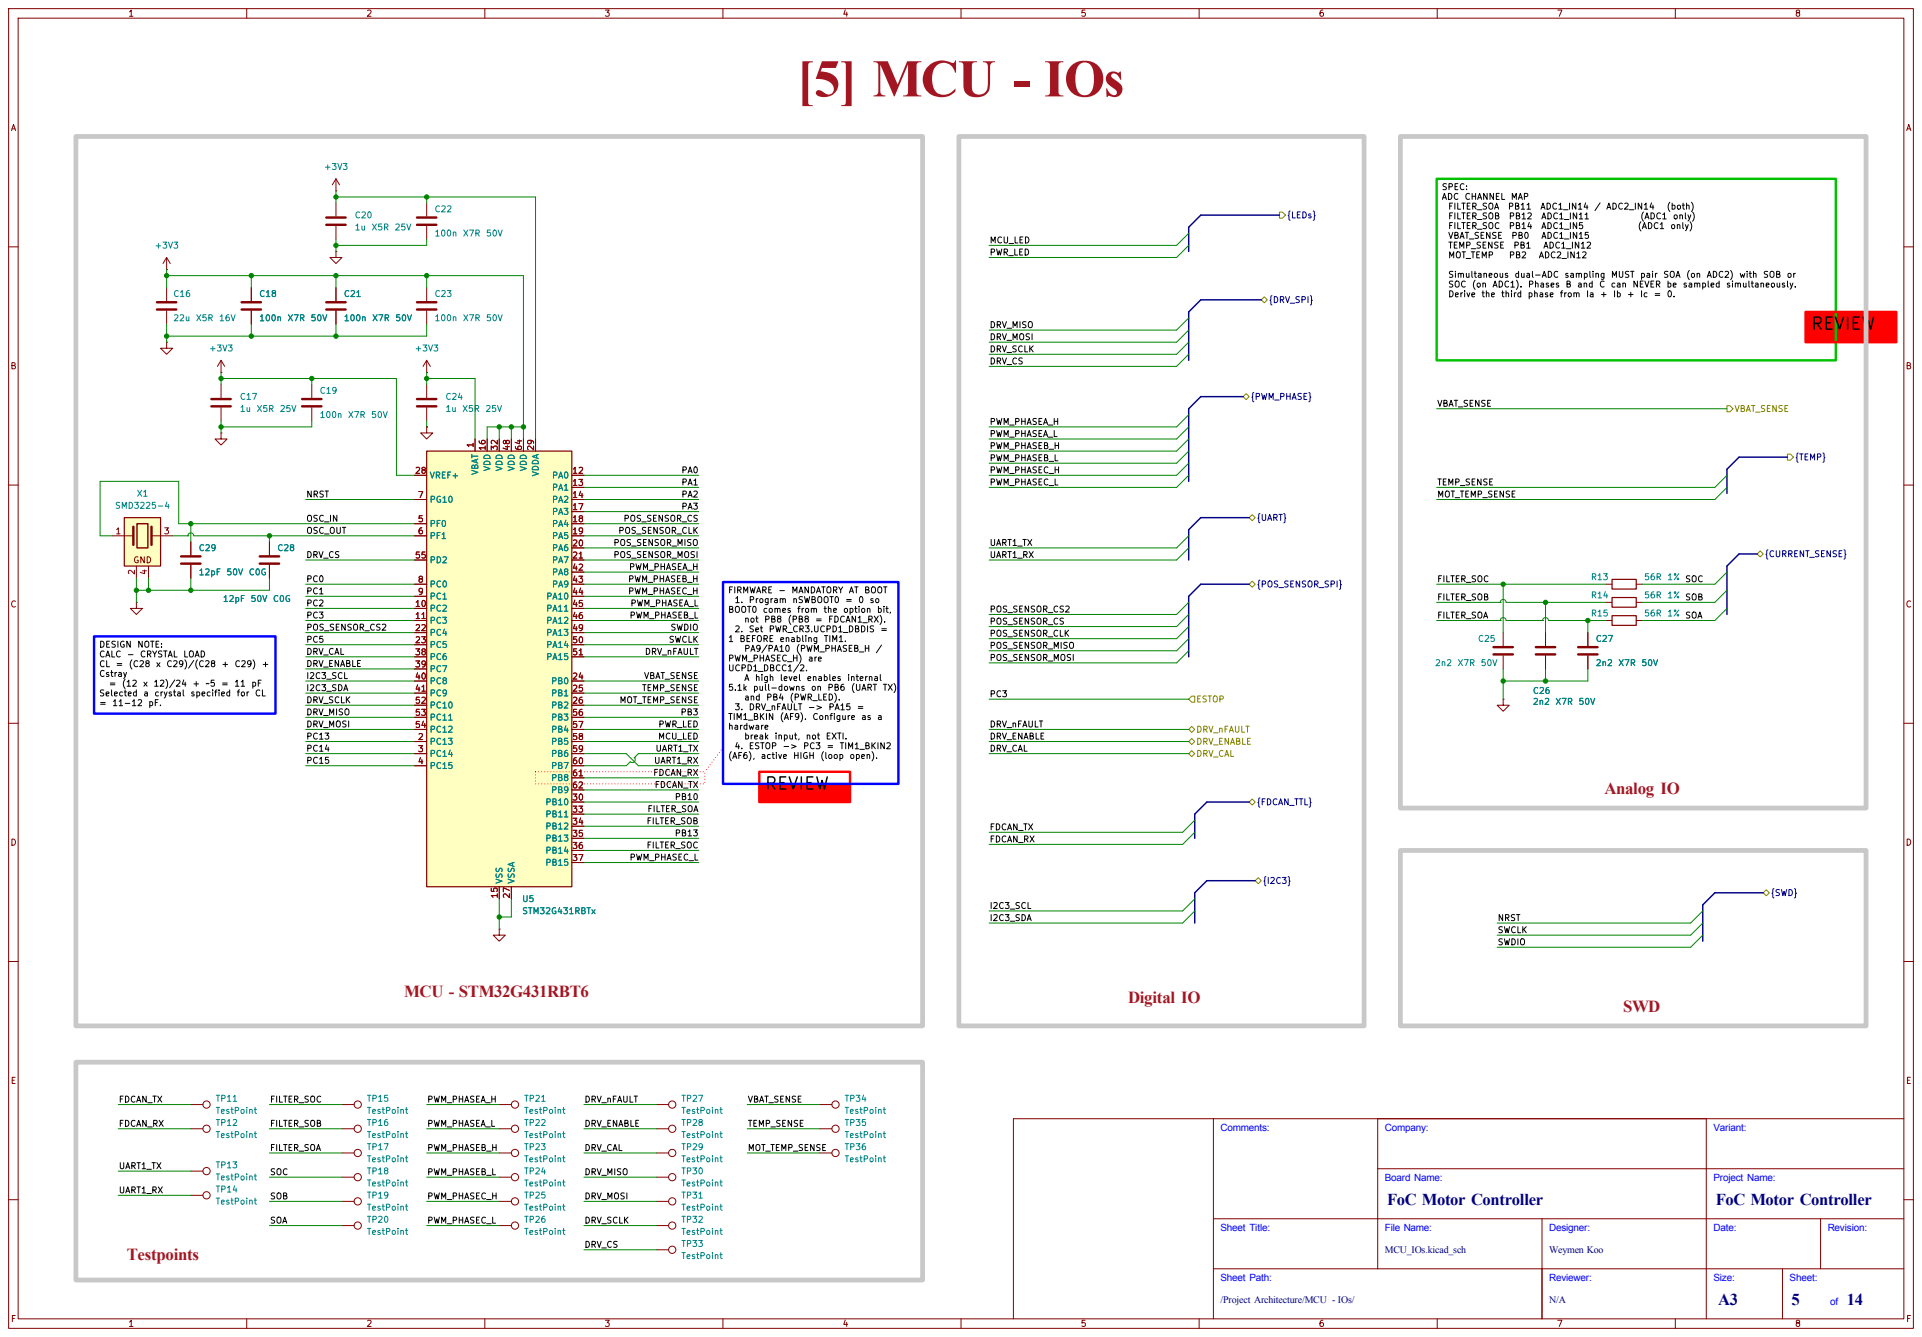
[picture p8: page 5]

SPEC: ADC CHANNEL MAP

FIRMWARE - MANDATORY AT BOOT 1. Program nSWBOOT0 = 0 so BOOT0 comes from the option bit, not PB8 (PB8 = FDCAN1_RX). 2. Set PWR_CR3.UCPD1_DBDIS =

DESIGN NOTE: CALC - CRYSTAL LOAD

Cstray = (12 x 12)/24 + ~5 = 11 pF Selected a crystal specified for CL = 11-12 pF.

PWM_PHASEC_H) are UCPD1_DBCC1/2. A high level enables internal 5.1k pull-downs on PB6 (UART TX) and PB4 (PWR_LED). 3. DRV_nFAULT -> PA15 =

TIM1_BKIN (AF9). Configure as a
hardware break input, not EXTI. 4. ESTOP -> PC3 = TIM1_BKIN2

(AF6), active HIGH (loop open).

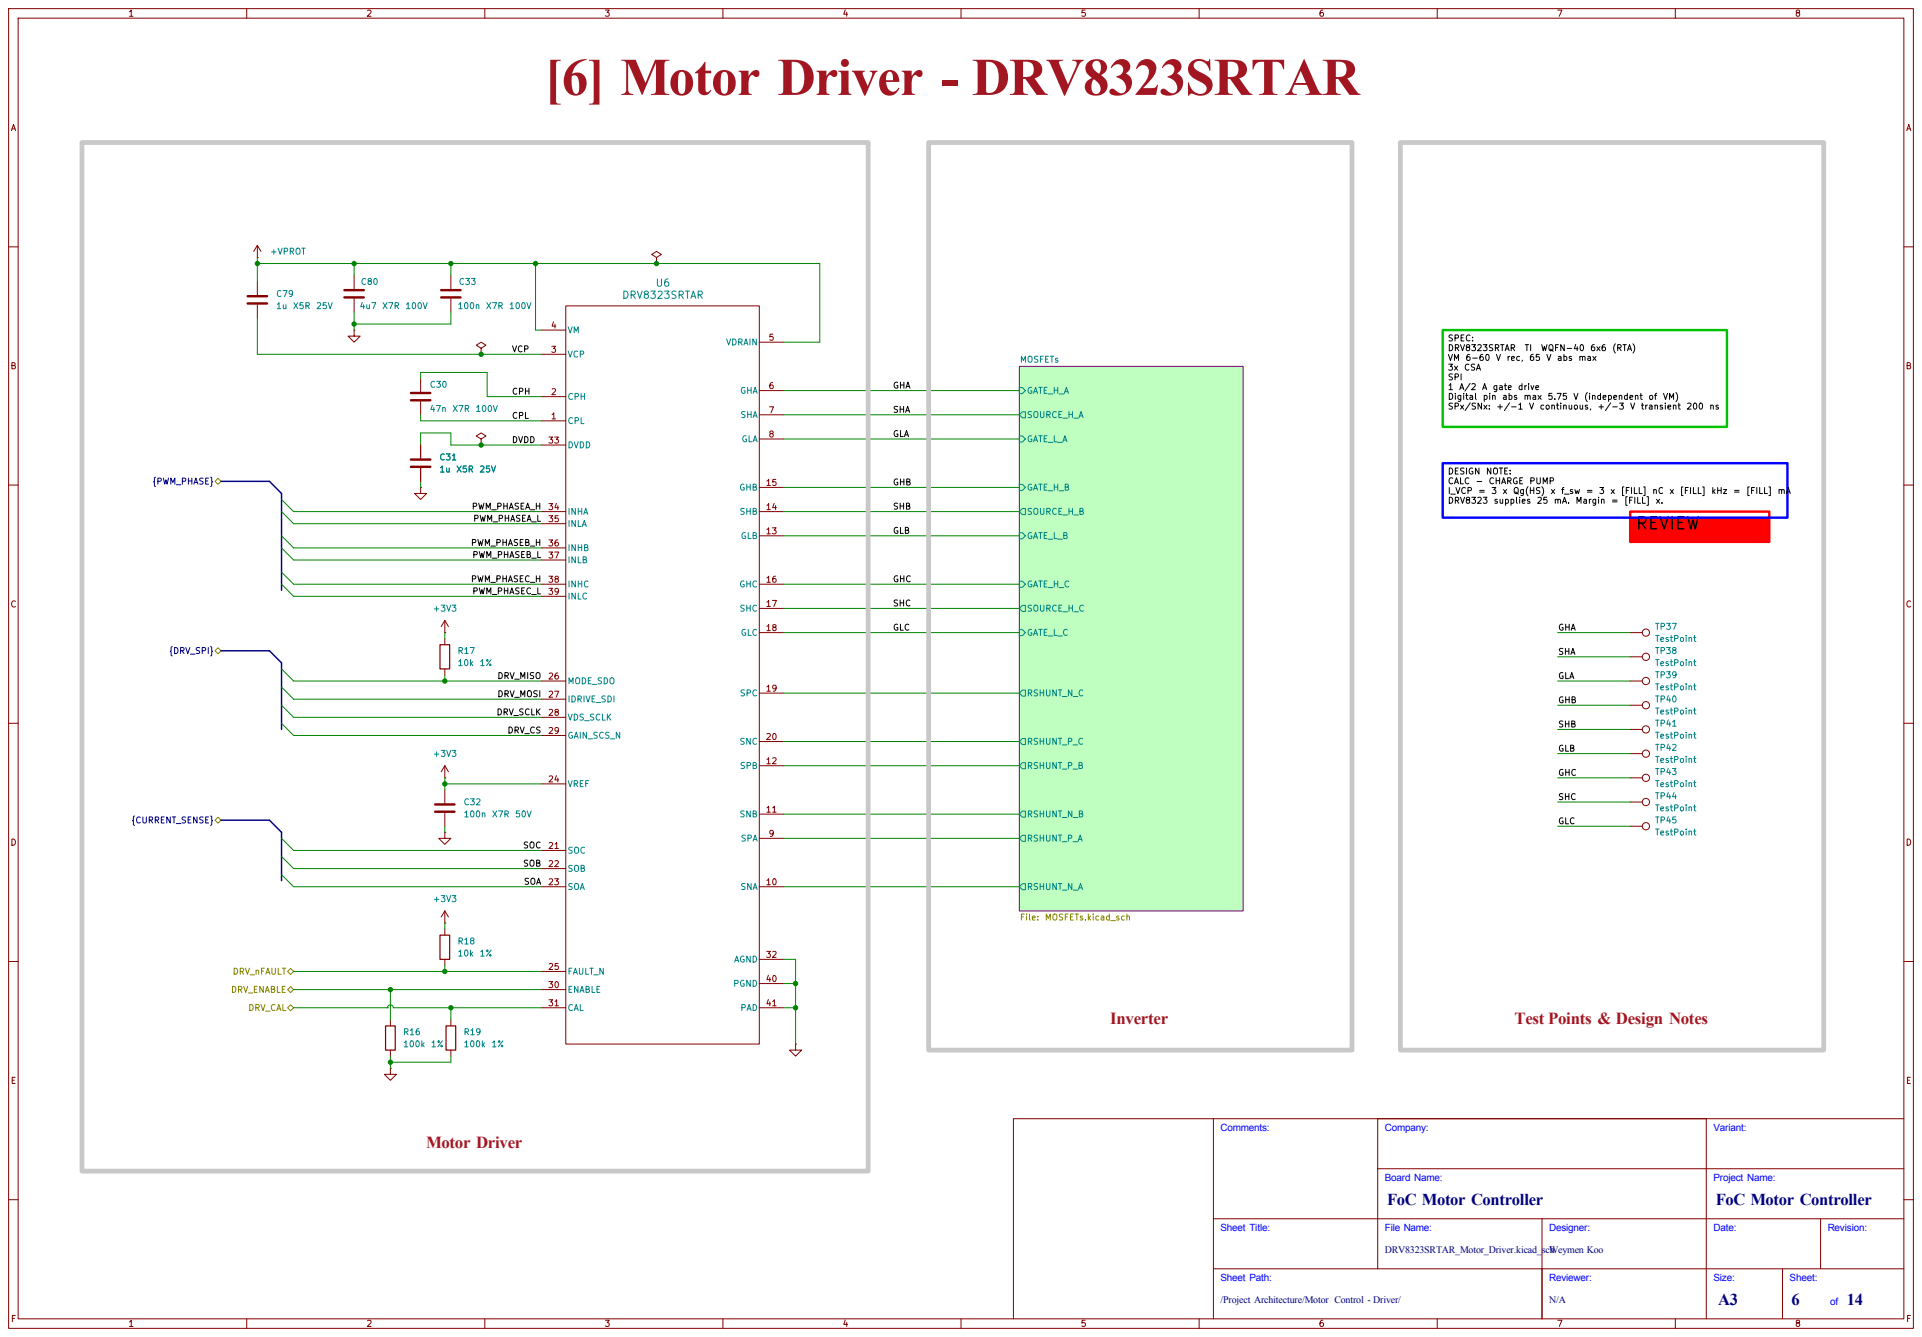
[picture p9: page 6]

SPx/SNx: +/-1 V continuous, +/-3 V transient 200 ns [6] Motor Driver - DRV8323SRTAR

SPEC: DRV8323SRTAR TI WQFN-40 6x6 (RTA) VM 6-60 V rec, 65 V abs max 3x CSA SPI 1 A/2 A gate drive Digital pin abs max 5.75 V (independent of VM)

I_VCP = 3 x Qg(HS) x f_sw = 3 x [FILL] nC x [FILL] kHz = [FILL] mA DRV8323 supplies 25 mA. Margin = [FILL] x. C31

DESIGN NOTE: CALC - CHARGE PUMP

SHC

GLC

/Project Architecture/Motor Control - Driver/ Sheet Path: Comments:

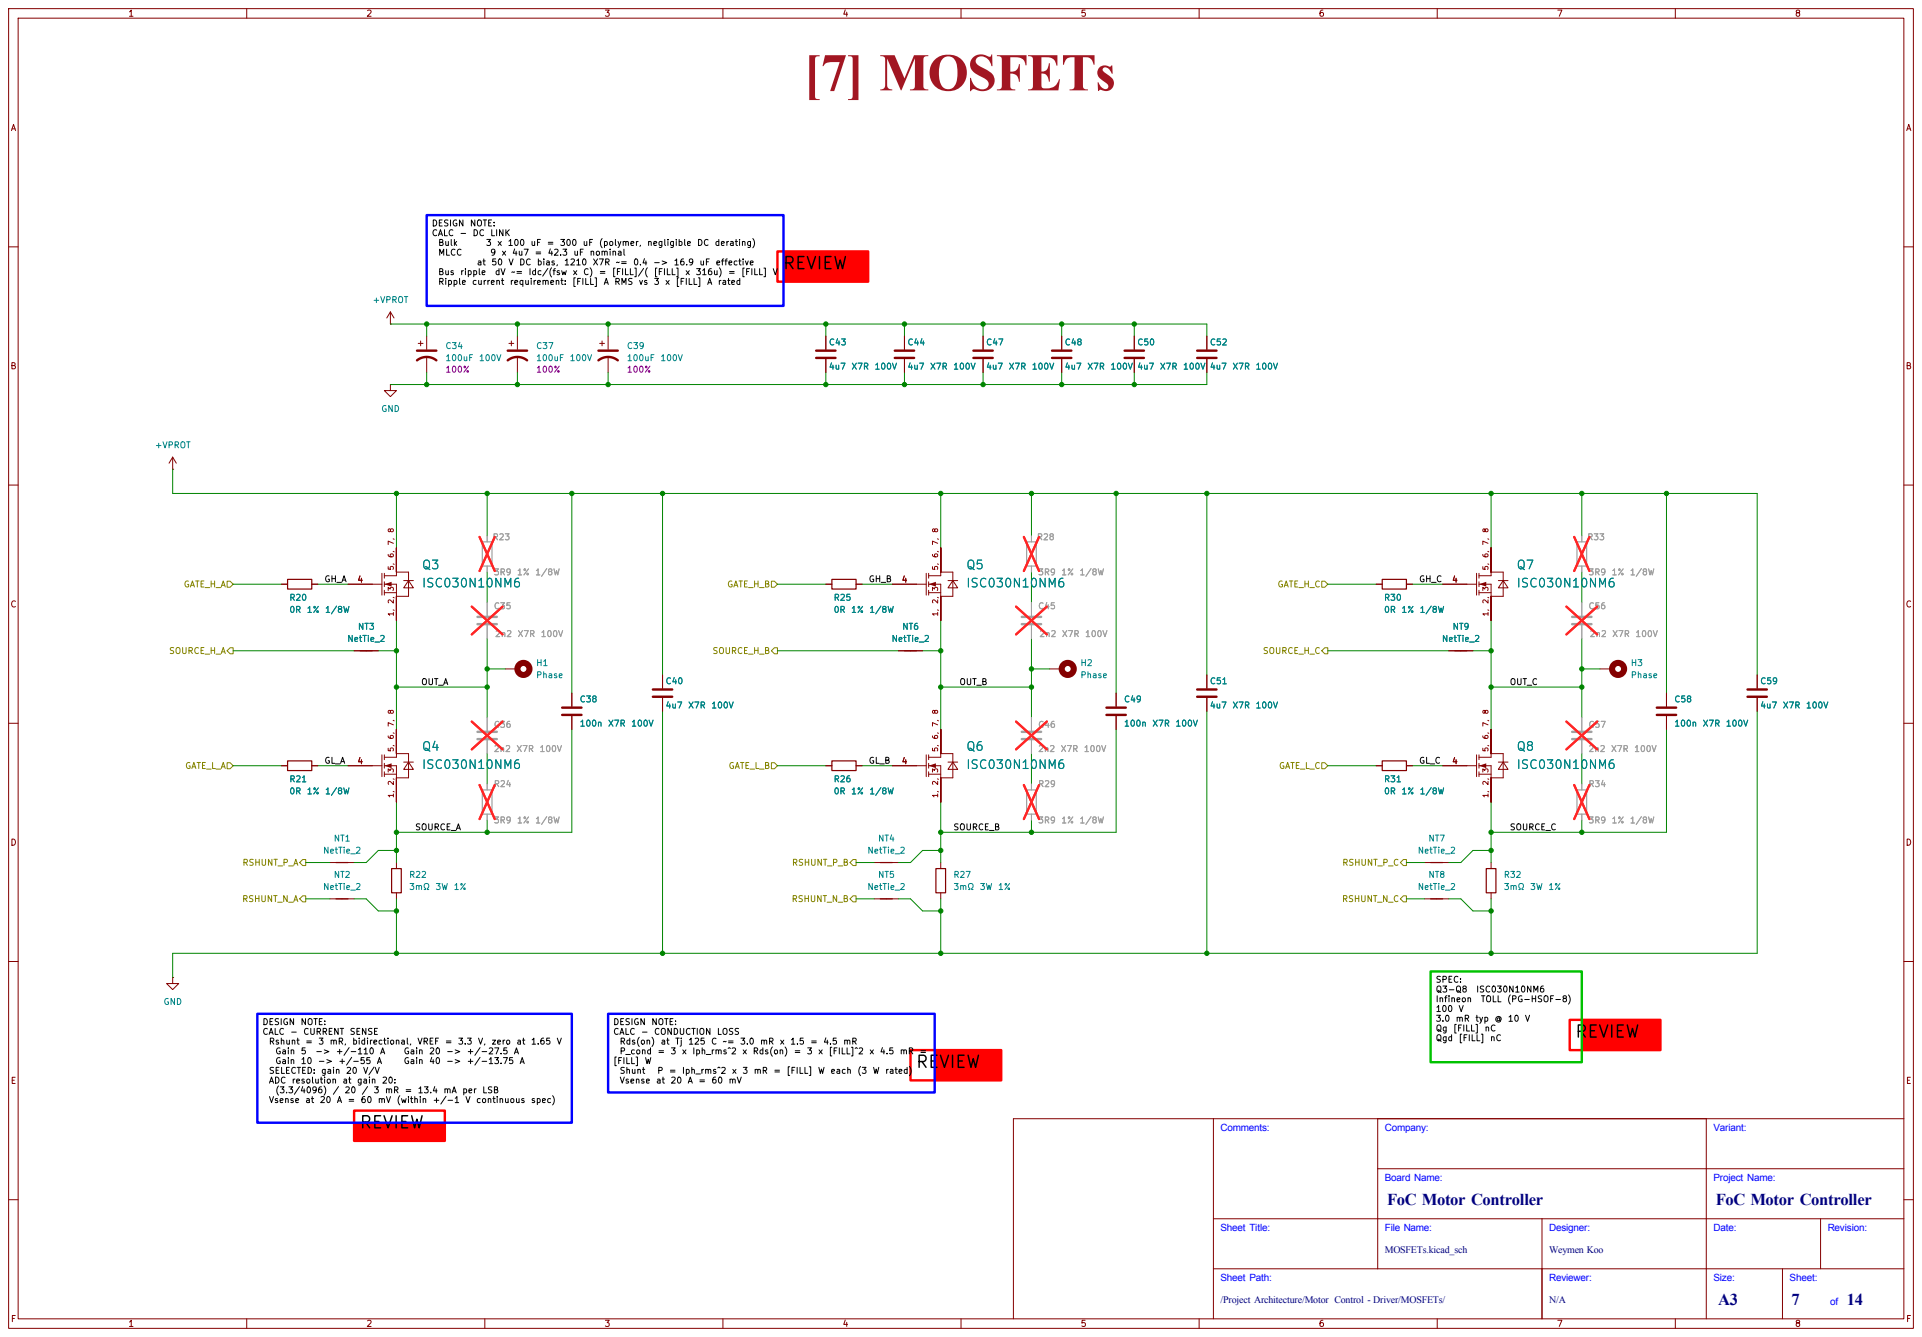
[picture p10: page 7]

DESIGN NOTE: CALC - DC LINK

/Project Architecture/Motor Control - Driver/MOSFETs/ Sheet Path: Comments: C36

Infineon TOLL (PG-HSOF-8) 100 V 3.0 mR typ @ 10 V Qg [FILL] nC Qgd [FILL] nC

DESIGN NOTE: CALC - CONDUCTION LOSS Rds(on) at Tj 125 C ~= 3.0 mR x 1.5 = 4.5 mR

REVIEW

P_cond = 3 x Iph_rms^2 x Rds(on) = 3 x [FILL]^2 x 4.5 mR =
[FILL] W

ADC resolution at gain 20: (3.3/4096) / 20 / 3 mR = 13.4 mA per LSB

Vsense at 20 A = 60 mV (within +/-1 V continuous spec)

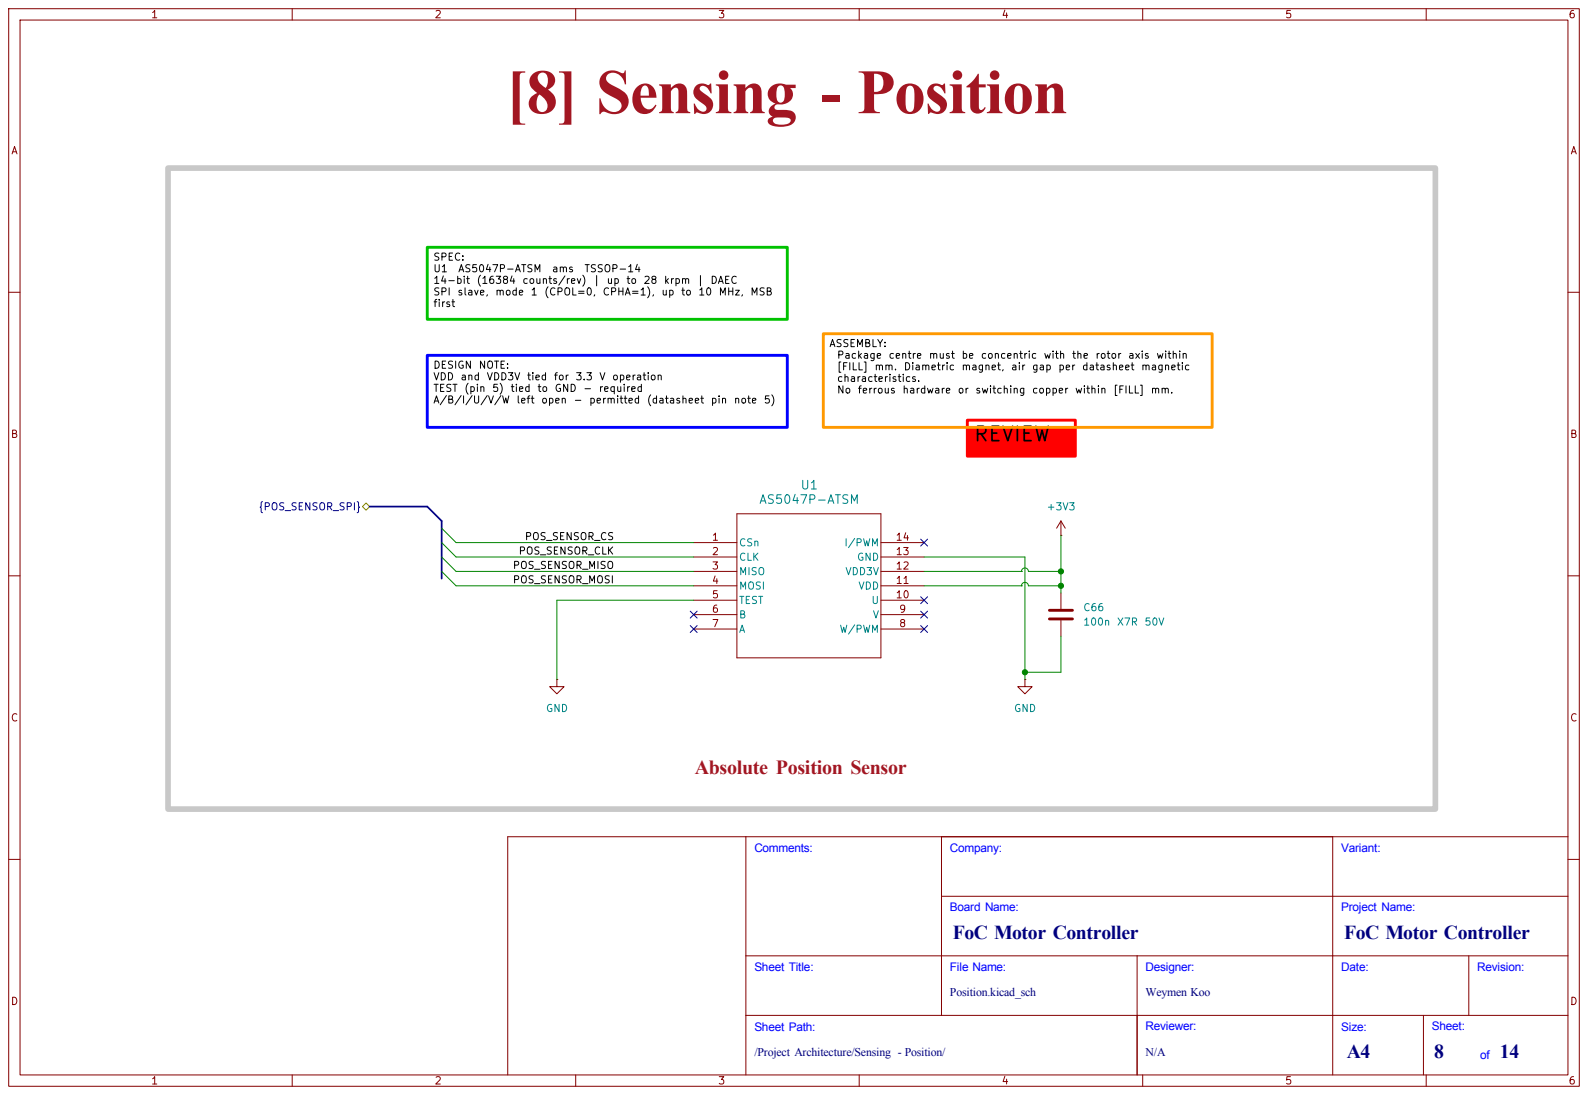
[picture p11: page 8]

characteristics. No ferrous hardware or switching copper within [FILL] mm. [8] Sensing - Position

SPEC: U1 AS5047P-ATSM ams TSSOP-14

14-bit (16384 counts/rev) | up to 28 krpm | DAEC
SPI slave, mode 1 (CPOL=0, CPHA=1), up to 10 MHz, MSB
first

DESIGN NOTE: VDD and VDD3V tied for 3.3 V operation

[FILL] mm. Diametric magnet, air gap per datasheet magnetic

TEST (pin 5) tied to GND - required

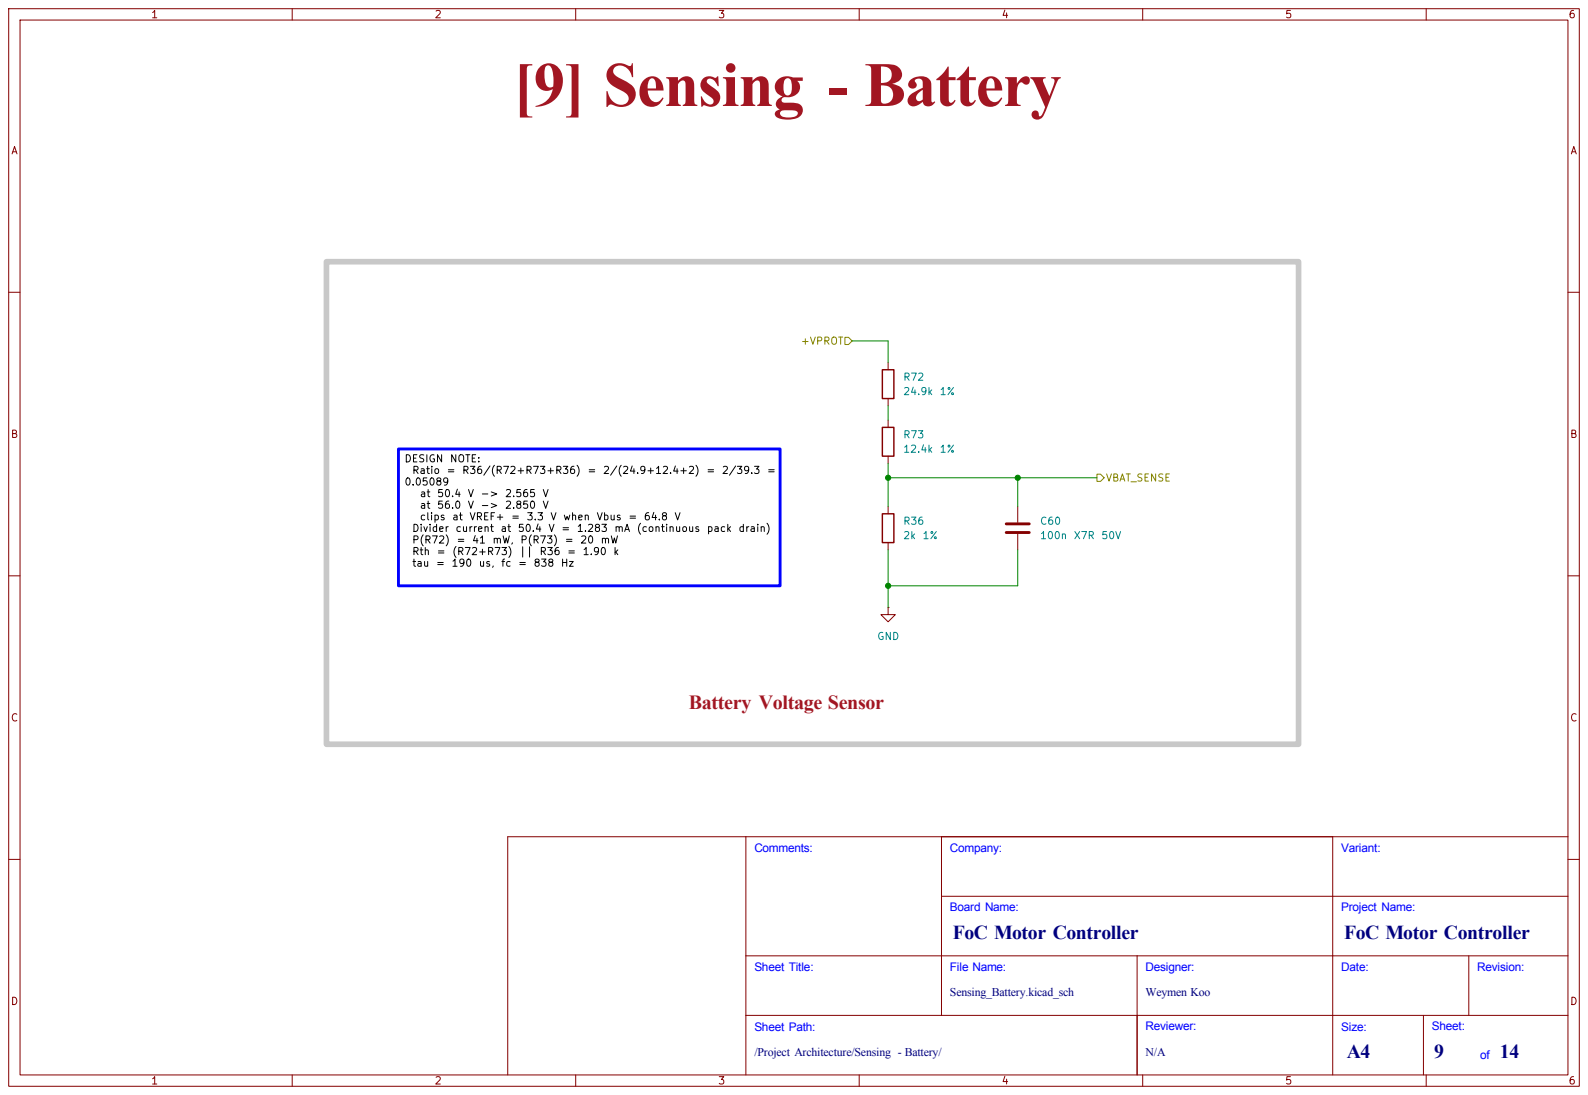
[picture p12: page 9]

clips at VREF+ = 3.3 V when Vbus = 64.8 V Divider current at 50.4 V = 1.283 mA (continuous pack drain) P(R72) = 41 mW, P(R73) = 20 mW

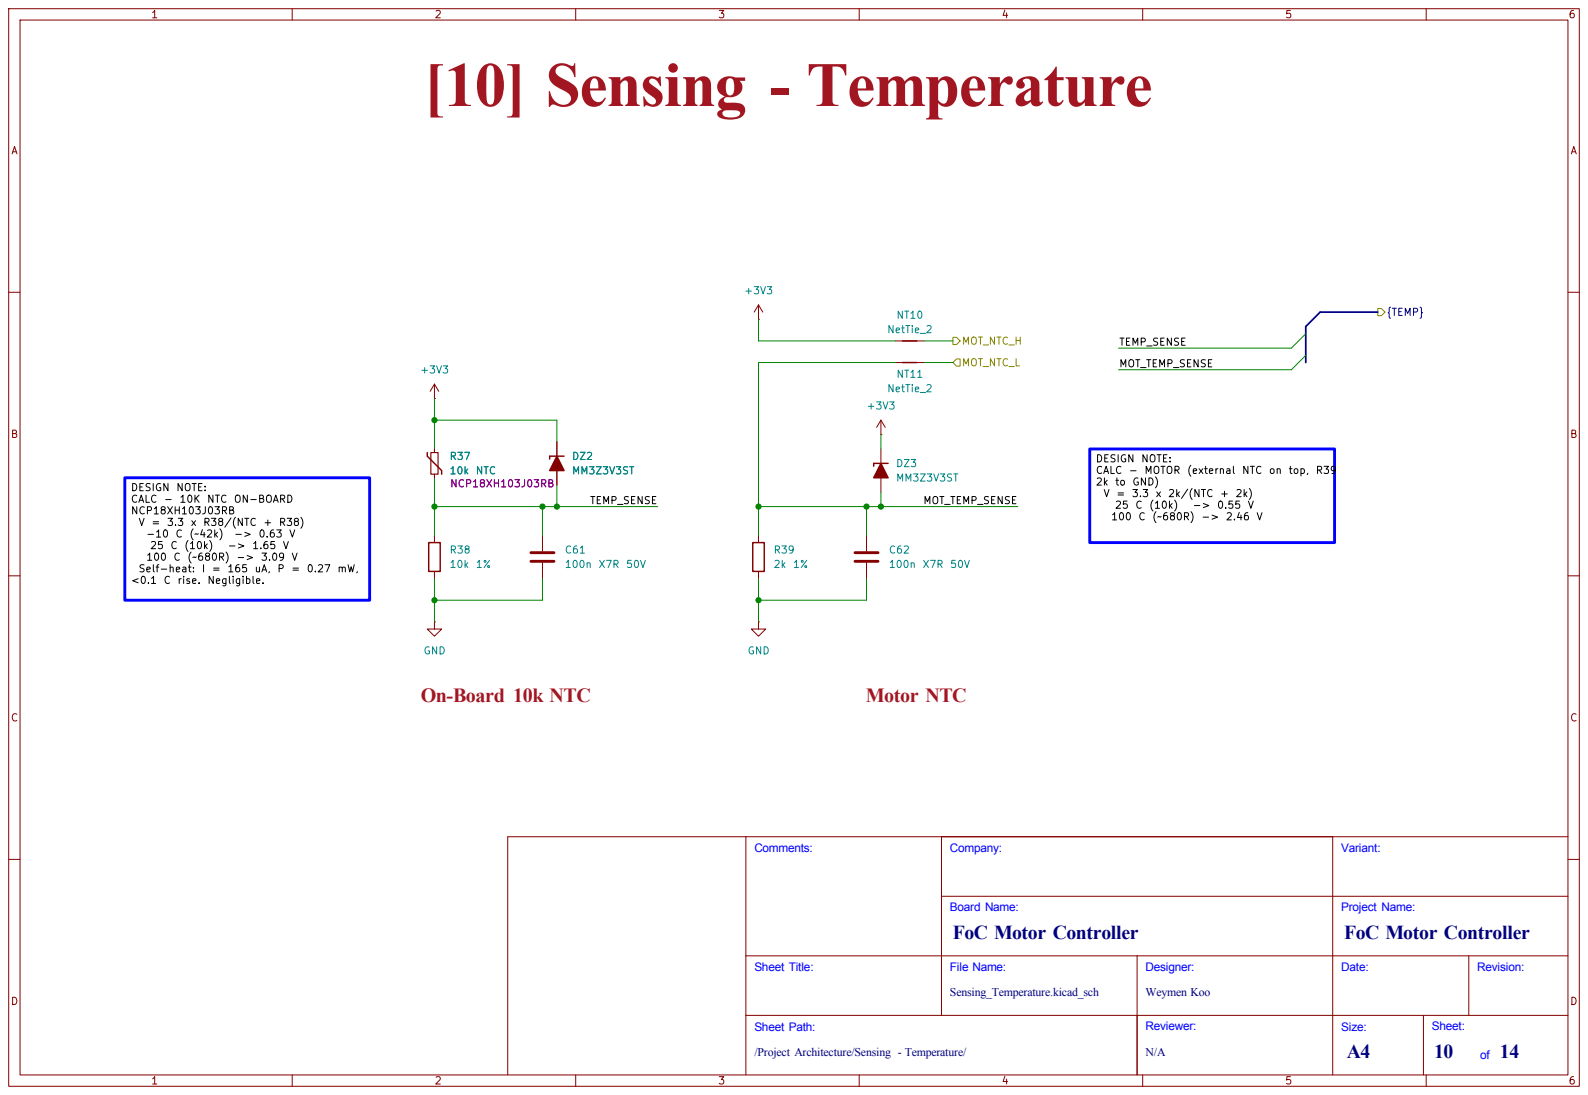
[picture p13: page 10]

DESIGN NOTE: CALC - MOTOR (external NTC on top, R39

2k to GND) V = 3.3 x 2k/(NTC + 2k) 25 C (10k) -> 0.55 V 100 C (~680R) -> 2.46 V DESIGN NOTE: CALC - 10K NTC ON-BOARD NCP18XH103J03RB

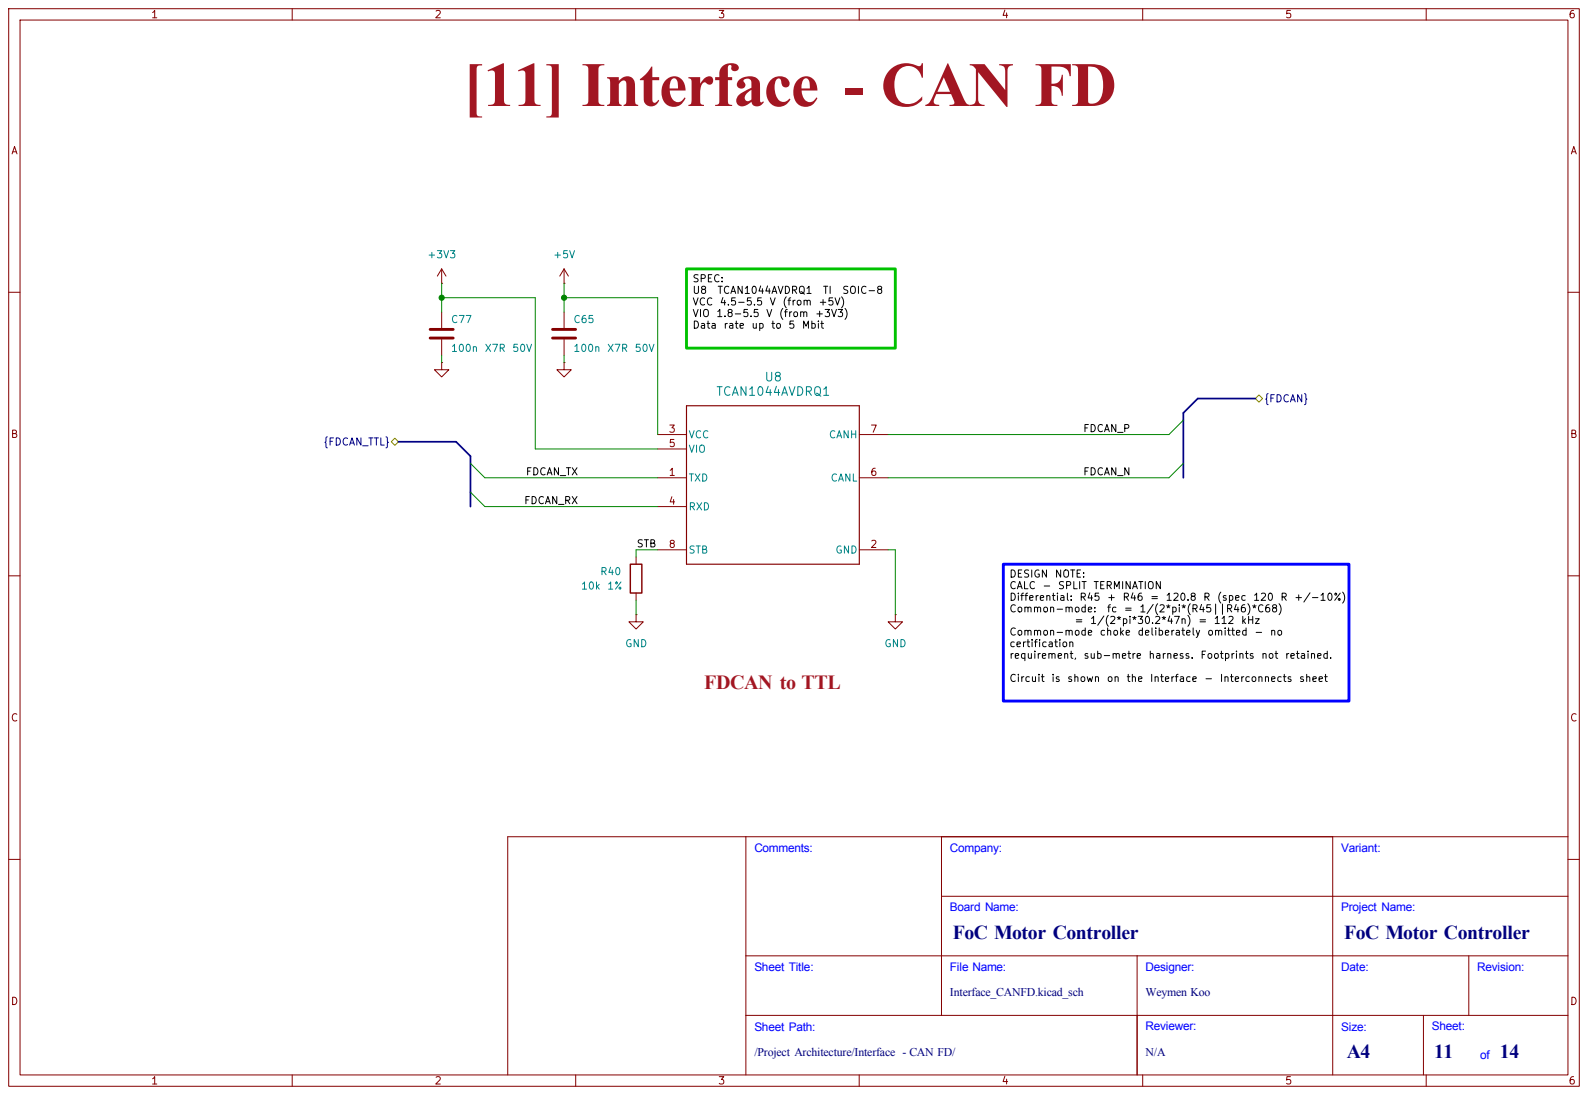
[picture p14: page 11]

requirement, sub-metre harness. Footprints not retained. Circuit is shown on the Interface - Interconnects sheet SPEC: U8 TCAN1044AVDRQ1 TI SOIC-8

DESIGN NOTE: CALC - SPLIT TERMINATION

Differential: R45 + R46 = 120.8 R (spec 120 R +/-10%) Common-mode: fc = 1/(2*pi*(R45||R46)*C68) = 1/(2*pi*30.2*47n) = 112 kHz Common-mode choke deliberately omitted - no

/Project Architecture/Interface - CAN FD/ Sheet Path: Comments:

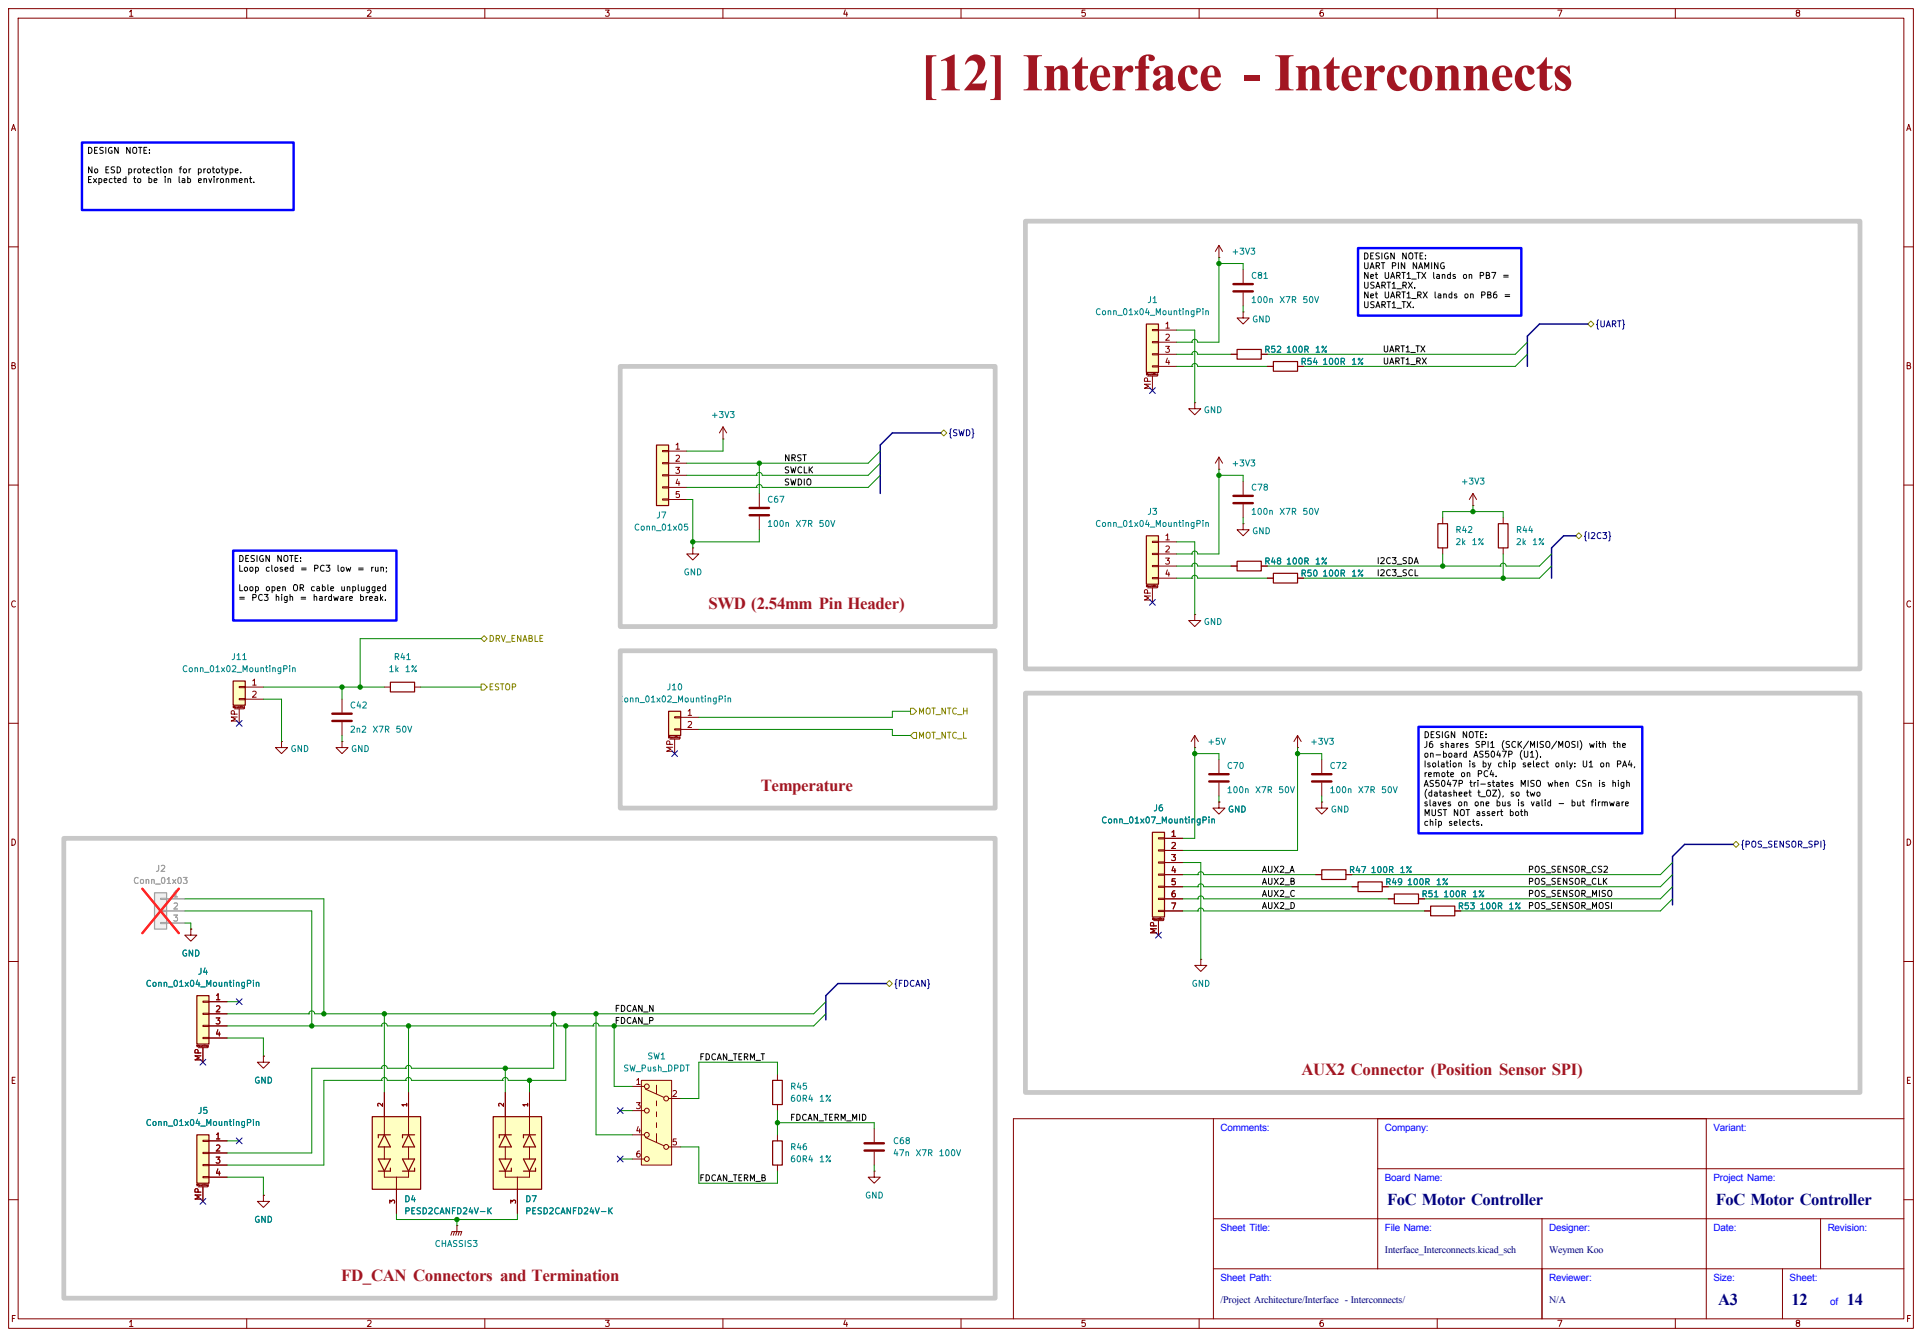
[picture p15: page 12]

chip selects. [12] Interface - Interconnects

USART1_TX. DESIGN NOTE: No ESD protection for prototype.

Expected to be in lab environment.

DESIGN NOTE: J6 shares SPI1 (SCK/MISO/MOSI) with the on-board AS5047P (U1).

Isolation is by chip select only: U1 on PA4, remote on PC4. AS5047P tri-states MISO when CSn is high

(datasheet t_OZ), so two
slaves on one bus is valid - but firmware MUST NOT assert both
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

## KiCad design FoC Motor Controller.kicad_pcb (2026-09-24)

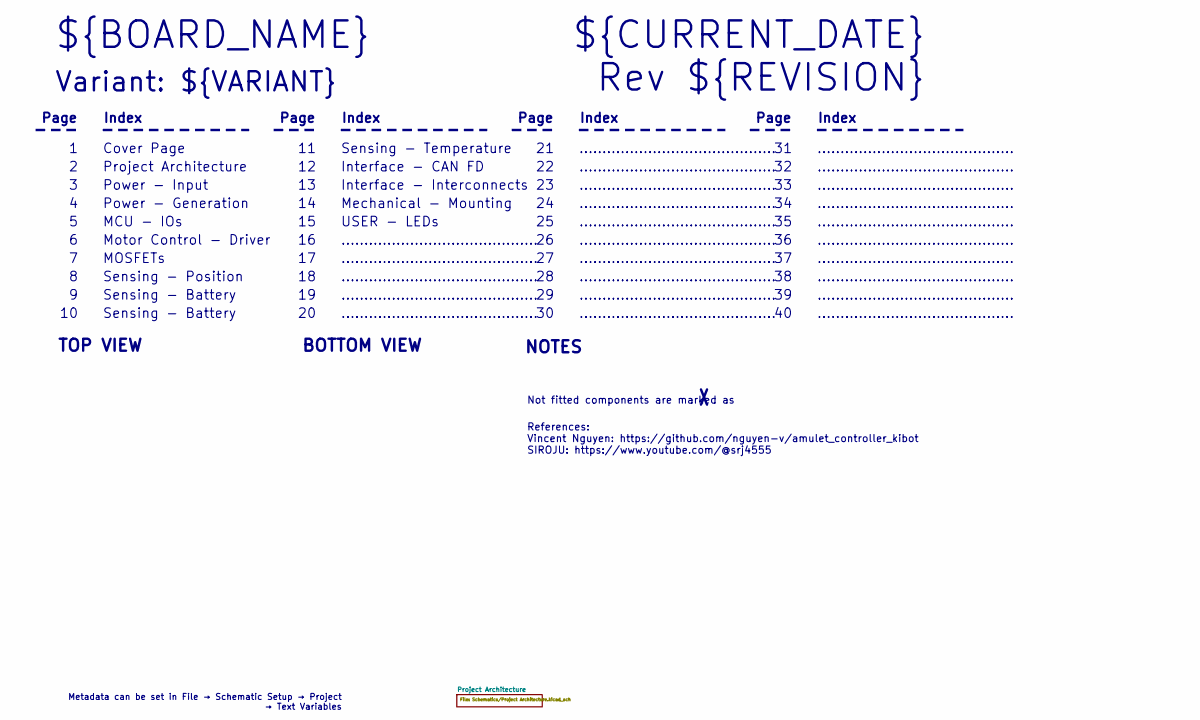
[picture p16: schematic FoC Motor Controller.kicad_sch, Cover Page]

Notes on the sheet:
BOTTOM VIEW
...........................................
Page
TOP VIEW
Sensing - Battery
Sensing - Position
Not fitted components are marked as
Index
Interface - Interconnects
Power - Generation
${CURRENT_DATE}
Variant: ${VARIANT}
Rev ${REVISION}
MCU - IOs
Sensing - Temperature
USER - LEDs
${BOARD_NAME}
Mechanical - Mounting
Motor Control - Driver
Project Architecture
References: Vincent Nguyen: https://github.com/nguyen-v/amulet_controller_kibot SIROJU: https://www.youtube.com/@srj4555
Cover Page
NOTES
Interface - CAN FD
Power - Input
MOSFETs
Metadata can be set in File → Schematic Setup → Project → Text Variables

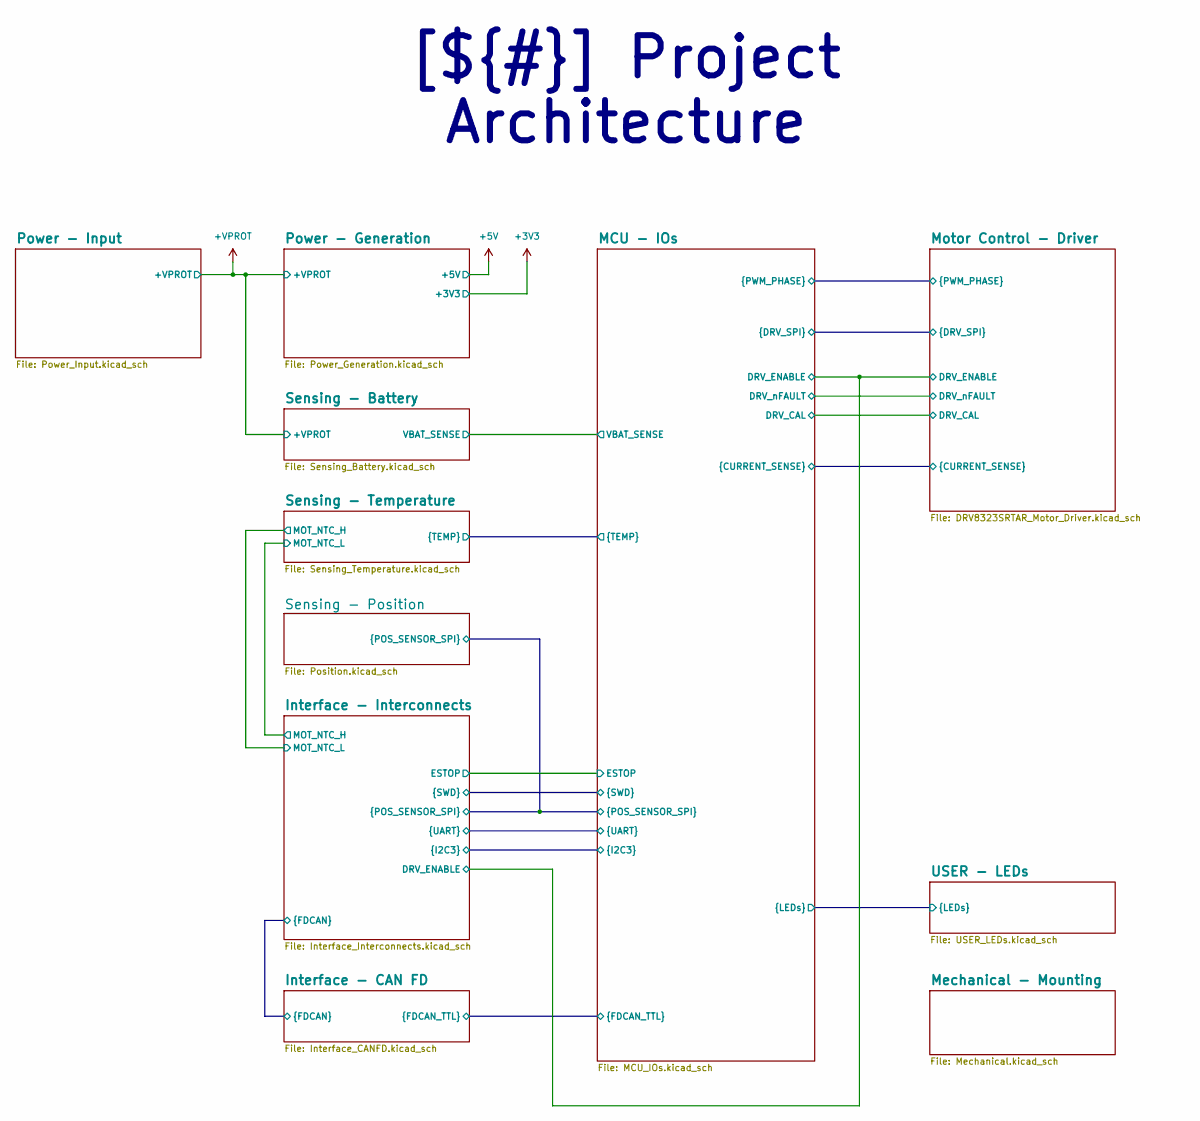
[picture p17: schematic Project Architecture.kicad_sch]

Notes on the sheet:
[${#}] ${TITLE}

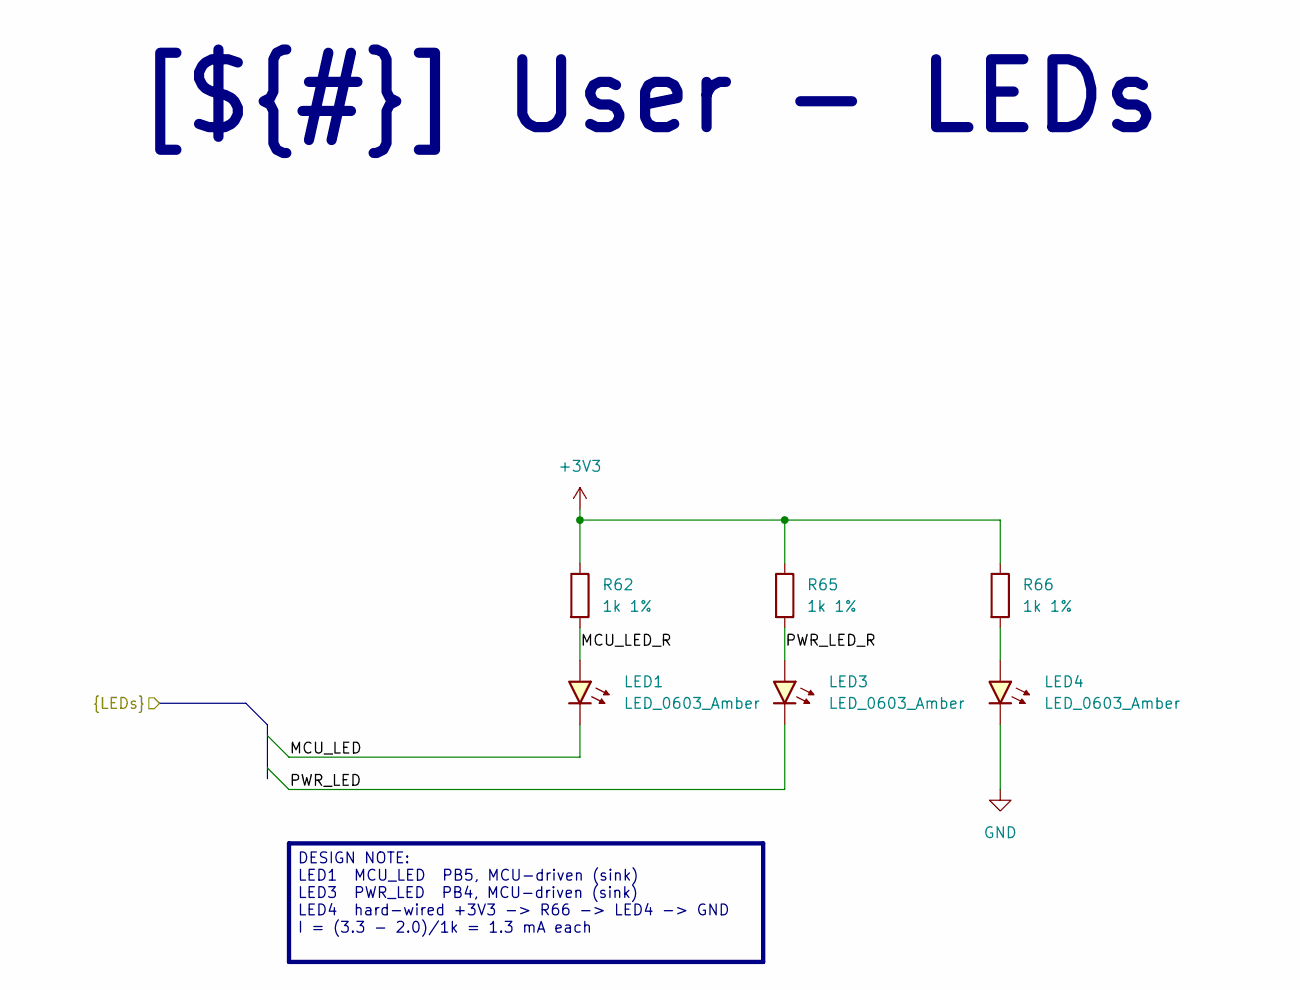
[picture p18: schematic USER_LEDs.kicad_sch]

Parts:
LED1, LED3, LED4: LED_0603_Amber; LED_0603_1608Metric
R62, R65, R66: 1k 1%; R_0402_1005Metric

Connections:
+3V3: R62.1, R65.1, R66.1; also elsewhere on the board
/Project Architecture/MCU - IOs/MCU_LED: LED1.1 (K); also elsewhere on the board
/Project Architecture/MCU - IOs/PWR_LED: LED3.1 (K); also elsewhere on the board
/Project Architecture/USER - LEDs/MCU_LED_R: LED1.2 (A), R62.2
/Project Architecture/USER - LEDs/PWR_LED_R: LED3.2 (A), R65.2
GND: LED4.1 (K); also elsewhere on the board
unnamed: LED4.2 (A), R66.2

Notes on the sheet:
[${#}] User - LEDs
DESIGN NOTE: LED1 MCU_LED PB5, MCU-driven (sink) LED3 PWR_LED PB4, MCU-driven (sink) LED4 hard-wired +3V3 -> R66 -> LED4 -> GND I = (3.3 - 2.0)/1k = 1.3 mA each

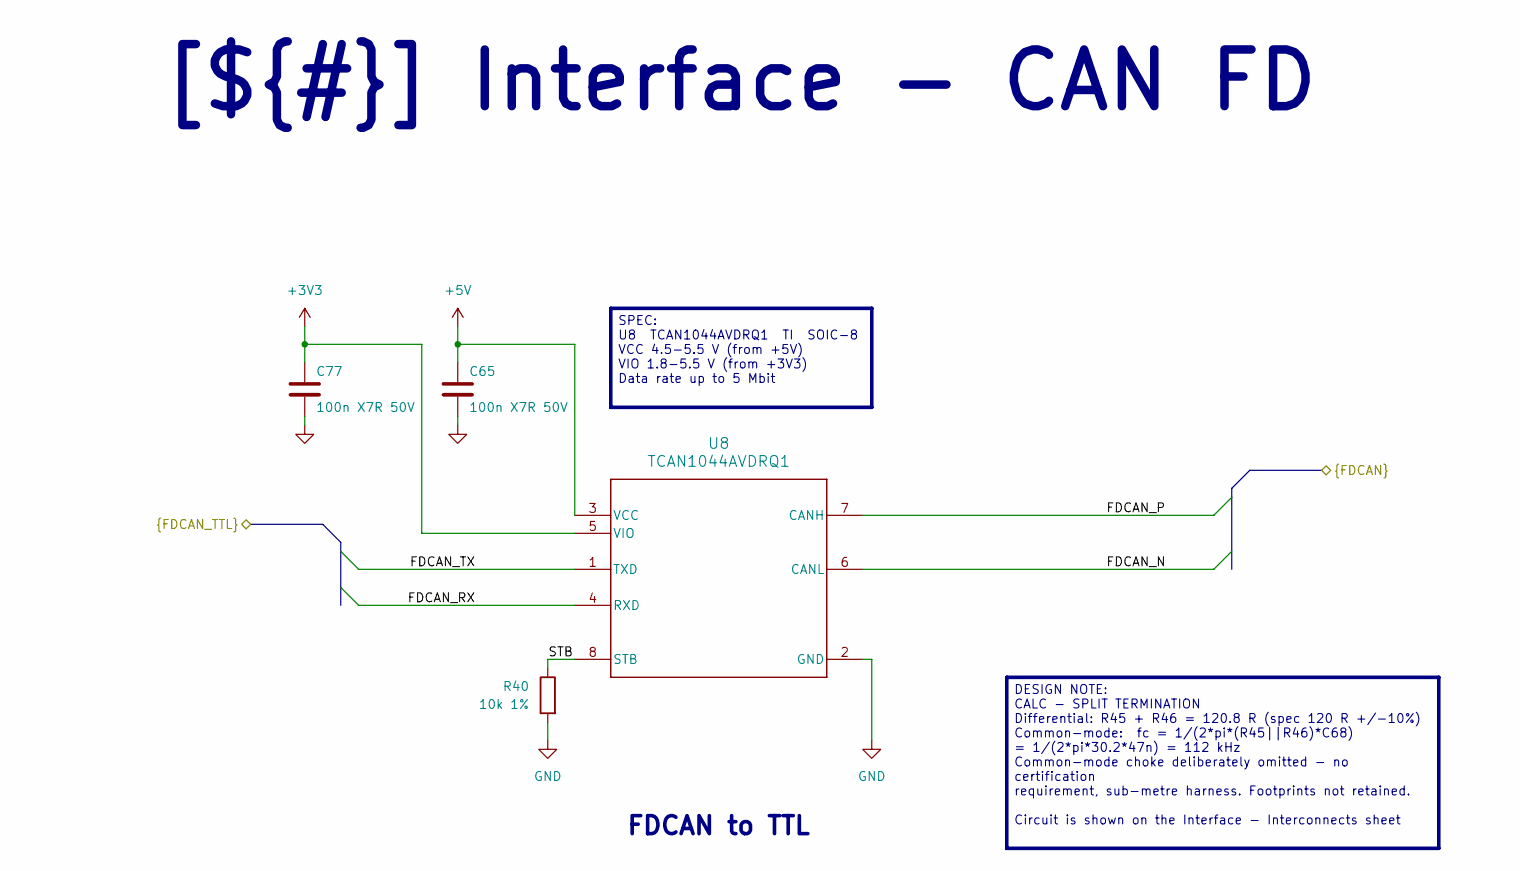
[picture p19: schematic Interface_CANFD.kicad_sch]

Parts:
C65, C77: 100n X7R 50V; C_0402_1005Metric
R40: 10k 1%; R_0402_1005Metric
U8: TCAN1044AVDRQ1; D0008A-IPC_A

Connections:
+3V3: C77.1, U8.5 (VIO); also elsewhere on the board
+5V: C65.1, U8.3 (VCC); also elsewhere on the board
/Project Architecture/Interface - CAN FD/FDCAN_N: U8.6 (CANL); also elsewhere on the board
/Project Architecture/Interface - CAN FD/FDCAN_P: U8.7 (CANH); also elsewhere on the board
/Project Architecture/Interface - CAN FD/FDCAN_RX: U8.4 (RXD); also elsewhere on the board
/Project Architecture/Interface - CAN FD/FDCAN_TX: U8.1 (TXD); also elsewhere on the board
/Project Architecture/Interface - CAN FD/STB: R40.1, U8.8 (STB)
GND: C65.2, C77.2, R40.2, U8.2 (GND); also elsewhere on the board

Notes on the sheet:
[${#}] Interface - CAN FD
FDCAN to TTL
DESIGN NOTE: CALC - SPLIT TERMINATION Differential: R45 + R46 = 120.8 R (spec 120 R +/-10%) Common-mode: fc = 1/(2*pi*(R45||R46)*C68) = 1/(2*pi*30.2*47n) = 112 kHz Common-mode choke deliberately omitted - no certification requirement, sub-metre harness. Footprints not retained. Circuit is shown on 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
SPEC: U8 TCAN1044AVDRQ1 TI SOIC-8 VCC 4.5-5.5 V (from +5V) VIO 1.8-5.5 V (from +3V3) Data rate up to 5 Mbit

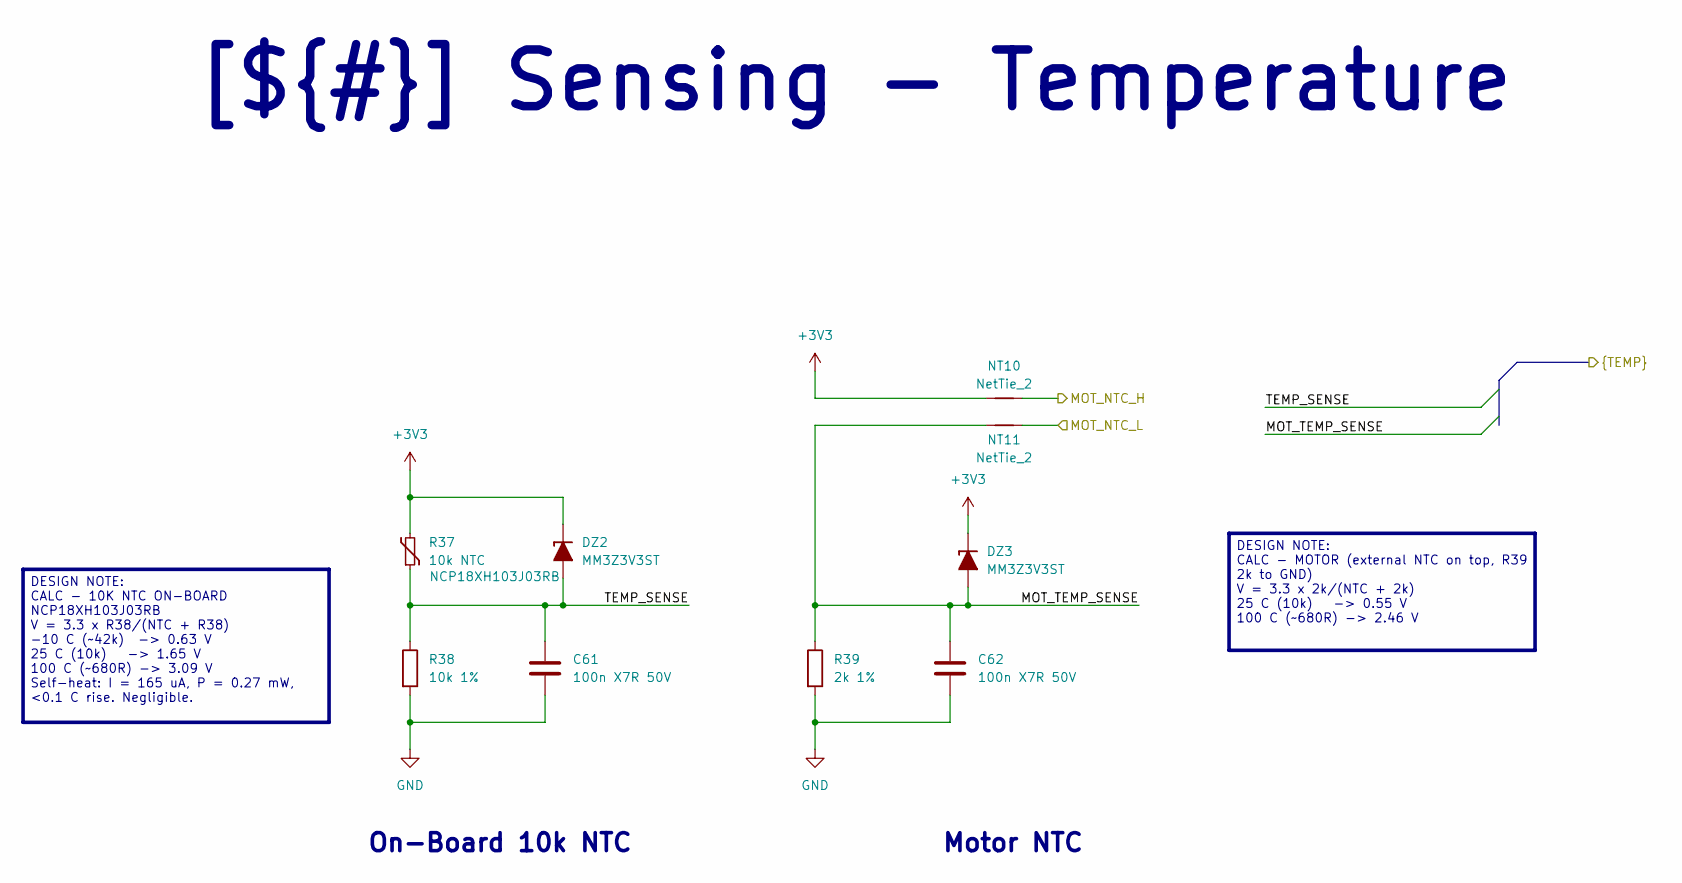
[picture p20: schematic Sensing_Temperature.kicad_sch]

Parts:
C61, C62: 100n X7R 50V; C_0402_1005Metric
DZ2, DZ3: MM3Z3V3ST; D_SOD-323
NT10, NT11: NetTie_2; NetTie-2_SMD_Pad0.5mm
R37: 10k NTC; R_0603_1608Metric; ManufacturerPartNumber NCP18XH103J03RB
R38: 10k 1%; R_0402_1005Metric
R39: 2k 1%; R_0402_1005Metric

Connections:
+3V3: DZ2.1 (K), DZ3.1 (K), NT10.1, R37.2; also elsewhere on the board
/Project Architecture/Interface - Interconnects/MOT_NTC_H: NT11.2; also elsewhere on the board
/Project Architecture/Interface - Interconnects/MOT_NTC_L: NT10.2; also elsewhere on the board
/Project Architecture/MCU - IOs/MOT_TEMP_SENSE: C62.1, DZ3.2 (A), NT11.1, R39.1; also elsewhere on the board
/Project Architecture/MCU - IOs/TEMP_SENSE: C61.1, DZ2.2 (A), R37.1, R38.1; also elsewhere on the board
GND: C61.2, C62.2, R38.2, R39.2; also elsewhere on the board

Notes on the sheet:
[${#}] Sensing - Temperature
On-Board 10k NTC
DESIGN NOTE: CALC - 10K NTC ON-BOARD NCP18XH103J03RB V = 3.3 x R38/(NTC + R38) -10 C (~42k) -> 0.63 V 25 C (10k) -> 1.65 V 100 C (~680R) -> 3.09 V Self-heat: I = 165 uA, P = 0.27 mW, <0.1 C rise. Negligible.
Motor NTC
DESIGN NOTE: CALC - MOTOR (external NTC on top, R39 2k to GND) V = 3.3 x 2k/(NTC + 2k) 25 C (10k) -> 0.55 V 100 C (~680R) -> 2.46 V

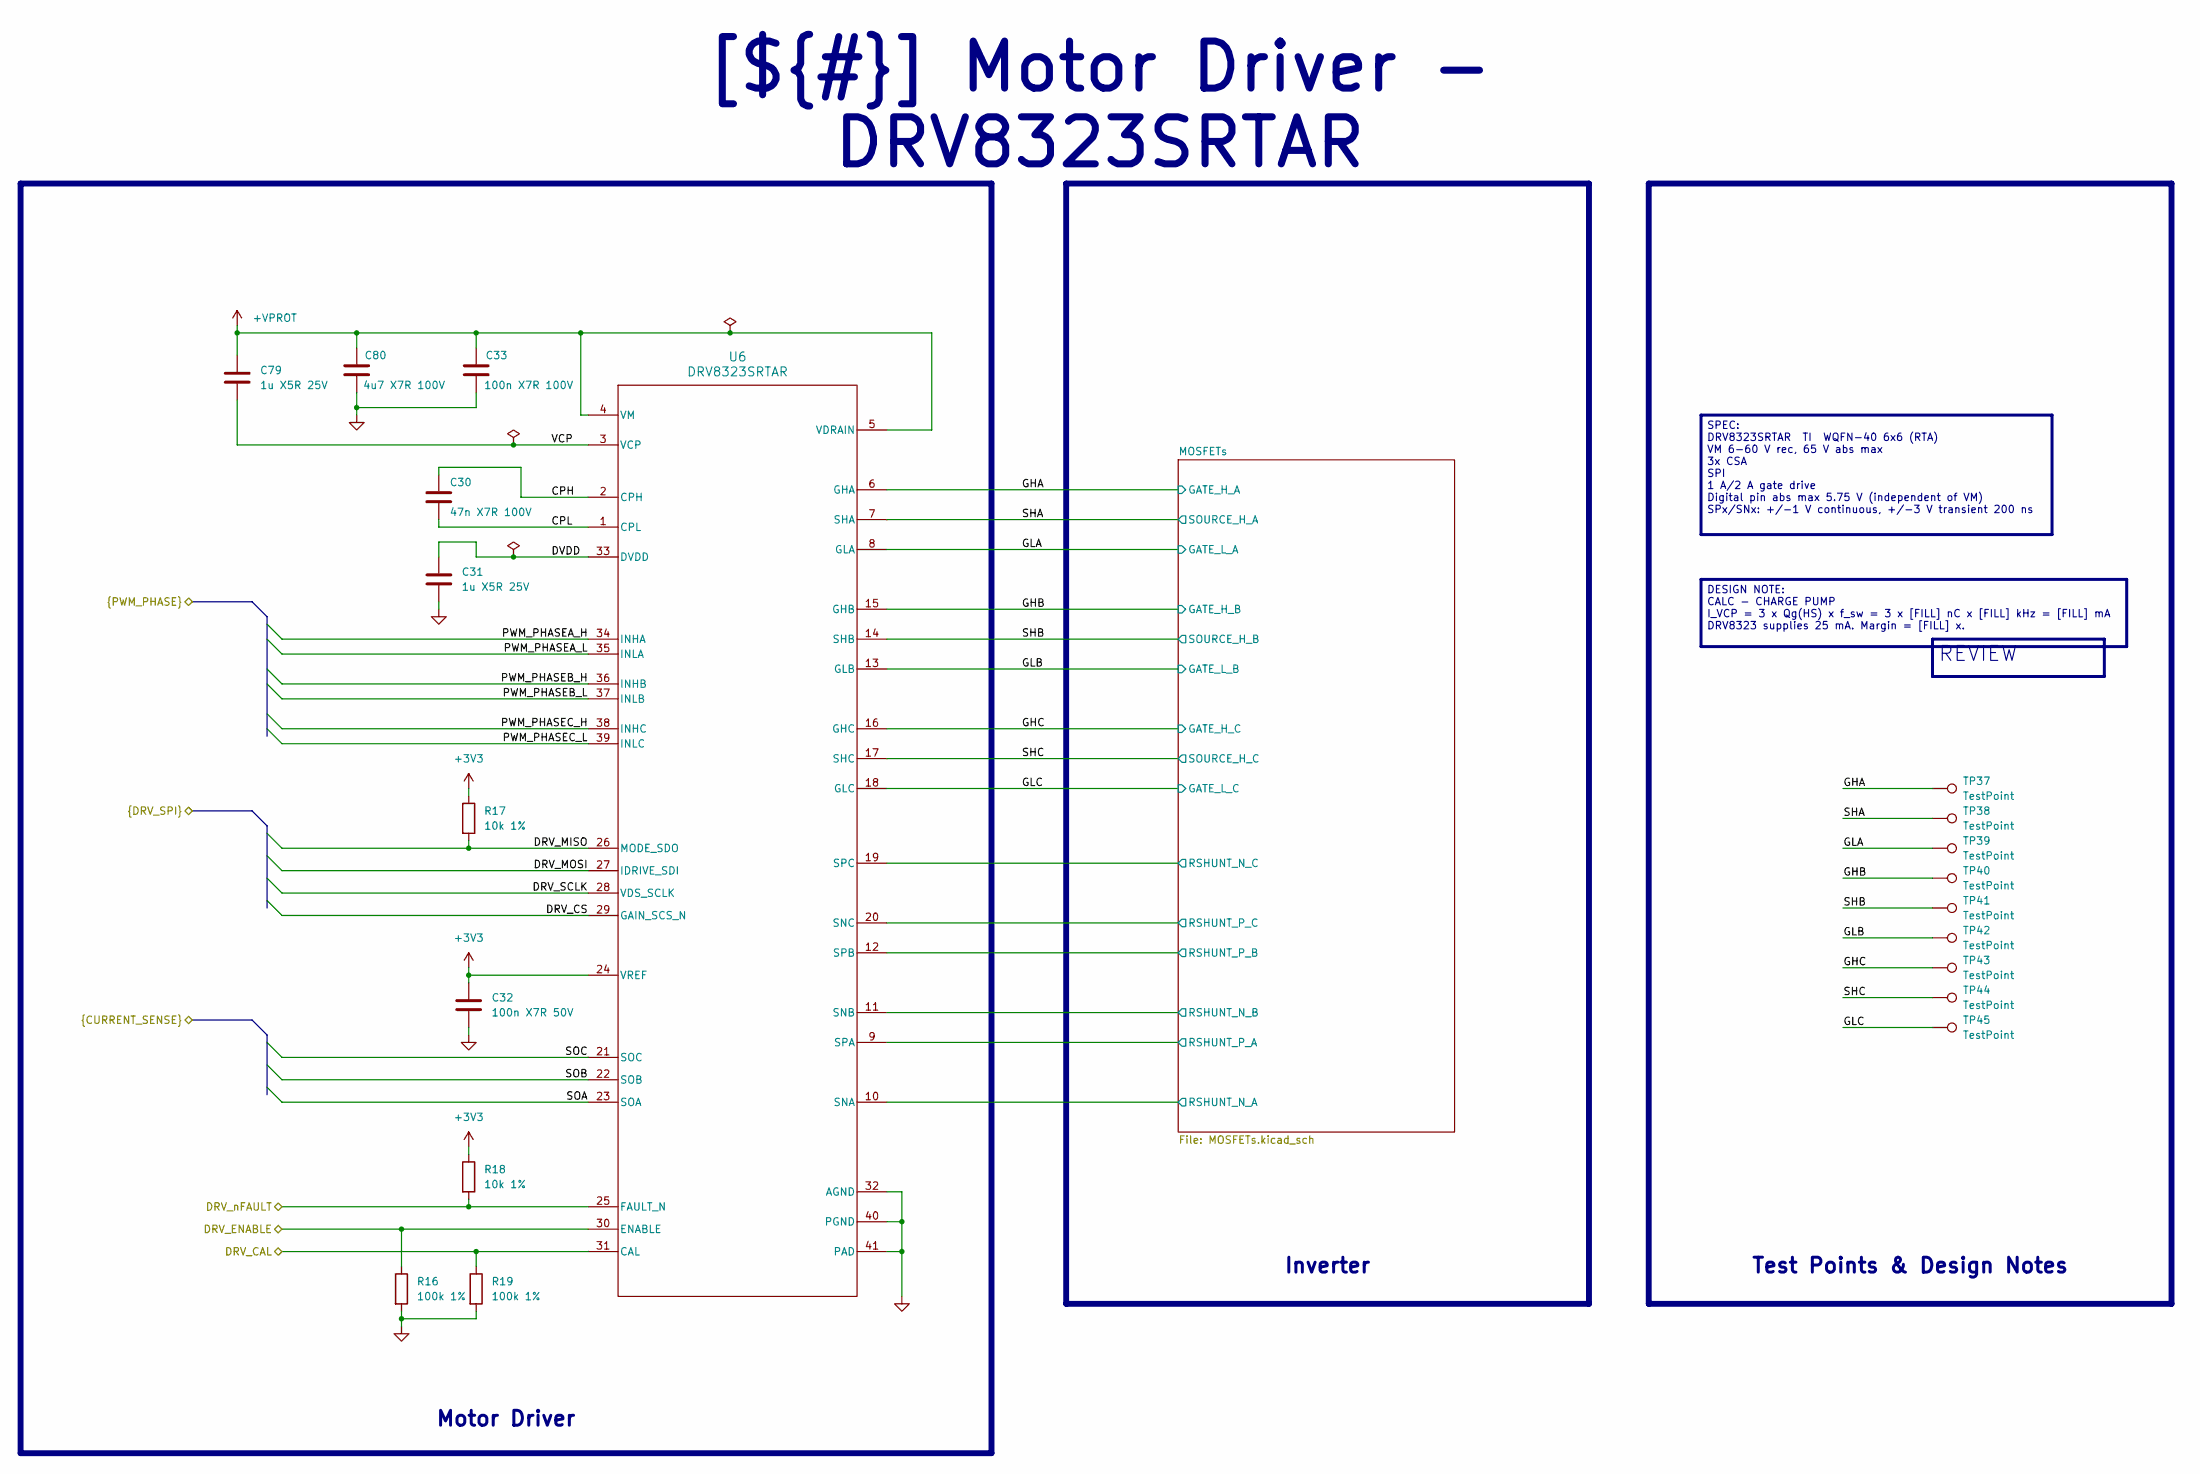
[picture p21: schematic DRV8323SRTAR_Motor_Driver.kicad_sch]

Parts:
C30: 47n X7R 100V; C_0603_1608Metric_Pad1.08x0.95mm_HandSolder
C31, C79: 1u X5R 25V; C_0603_1608Metric
C32: 100n X7R 50V; C_0402_1005Metric
C33: 100n X7R 100V; C_0603_1608Metric_Pad1.08x0.95mm_HandSolder
C80: 4u7 X7R 100V; C_1210_3225Metric_Pad1.33x2.70mm_HandSolder
R16, R19: 100k 1%; R_0402_1005Metric
R17, R18: 10k 1%; R_0402_1005Metric
TP37, TP38, TP39, TP40, TP41, TP42, TP43, TP44, TP45: TestPoint; TestPoint-0.5mm
U6: DRV8323SRTAR; RTA0040B

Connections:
+3V3: C32.1, R17.1, R18.1, U6.24 (VREF); also elsewhere on the board
+VPROT: C33.1, C79.1, C80.1, U6.4 (VM), U6.5 (VDRAIN); also elsewhere on the board
/Project Architecture/MCU - IOs/DRV_CAL: R19.1, U6.31 (CAL); also elsewhere on the board
/Project Architecture/MCU - IOs/DRV_CS: U6.29 (GAIN_SCS_N); also elsewhere on the board
/Project Architecture/MCU - IOs/DRV_ENABLE: R16.1, U6.30 (ENABLE); also elsewhere on the board
/Project Architecture/MCU - IOs/DRV_MISO: R17.2, U6.26 (MODE_SDO); also elsewhere on the board
/Project Architecture/MCU - IOs/DRV_MOSI: U6.27 (IDRIVE_SDI); also elsewhere on the board
/Project Architecture/MCU - IOs/DRV_SCLK: U6.28 (VDS_SCLK); also elsewhere on the board
/Project Architecture/MCU - IOs/DRV_nFAULT: R18.2, U6.25 (FAULT_N); also elsewhere on the board
/Project Architecture/MCU - IOs/PWM_PHASEA_H: U6.34 (INHA); also elsewhere on the board
/Project Architecture/MCU - IOs/PWM_PHASEA_L: U6.35 (INLA); also elsewhere on the board
/Project Architecture/MCU - IOs/PWM_PHASEB_H: U6.36 (INHB); also elsewhere on the board
/Project Architecture/MCU - IOs/PWM_PHASEB_L: U6.37 (INLB); also elsewhere on the board
/Project Architecture/MCU - IOs/PWM_PHASEC_H: U6.38 (INHC); also elsewhere on the board
/Project Architecture/MCU - IOs/PWM_PHASEC_L: U6.39 (INLC); also elsewhere on the board
/Project Architecture/MCU - IOs/SOA: U6.23 (SOA); also elsewhere on the board
/Project Architecture/MCU - IOs/SOB: U6.22 (SOB); also elsewhere on the board
/Project Architecture/MCU - IOs/SOC: U6.21 (SOC); also elsewhere on the board
/Project Architecture/Motor Control - Driver/CPH: C30.1, U6.2 (CPH)
/Project Architecture/Motor Control - Driver/CPL: C30.2, U6.1 (CPL)
/Project Architecture/Motor Control - Driver/DVDD: C31.1, U6.33 (DVDD)
/Project Architecture/Motor Control - Driver/GHA: TP37.1 (1_1), U6.6 (GHA); also elsewhere on the board
/Project Architecture/Motor Control - Driver/GHB: TP40.1 (1_1), U6.15 (GHB); also elsewhere on the board
/Project Architecture/Motor Control - Driver/GHC: TP43.1 (1_1), U6.16 (GHC); also elsewhere on the board
/Project Architecture/Motor Control - Driver/GLA: TP39.1 (1_1), U6.8 (GLA); also elsewhere on the board
/Project Architecture/Motor Control - Driver/GLB: TP42.1 (1_1), U6.13 (GLB); also elsewhere on the board
/Project Architecture/Motor Control - Driver/GLC: TP45.1 (1_1), U6.18 (GLC); also elsewhere on the board
/Project Architecture/Motor Control - Driver/MOSFETs/RSHUNT_N_A: U6.10 (SNA); also elsewhere on the board
/Project Architecture/Motor Control - Driver/MOSFETs/RSHUNT_N_B: U6.11 (SNB); also elsewhere on the board
/Project Architecture/Motor Control - Driver/MOSFETs/RSHUNT_N_C: U6.19 (SPC); also elsewhere on the board
/Project Architecture/Motor Control - Driver/MOSFETs/RSHUNT_P_A: U6.9 (SPA); also elsewhere on the board
/Project Architecture/Motor Control - Driver/MOSFETs/RSHUNT_P_B: U6.12 (SPB); also elsewhere on the board
/Project Architecture/Motor Control - Driver/MOSFETs/RSHUNT_P_C: U6.20 (SNC); also elsewhere on the board
/Project Architecture/Motor Control - Driver/SHA: TP38.1 (1_1), U6.7 (SHA); also elsewhere on the board
/Project Architecture/Motor Control - Driver/SHB: TP41.1 (1_1), U6.14 (SHB); also elsewhere on the board
/Project Architecture/Motor Control - Driver/SHC: TP44.1 (1_1), U6.17 (SHC); also elsewhere on the board
/Project Architecture/Motor Control - Driver/VCP: C79.2, U6.3 (VCP)
GND: C31.2, C32.2, C33.2, C80.2, R16.2, R19.2, U6.32 (AGND), U6.40 (PGND), U6.41 (PAD); also elsewhere on the board

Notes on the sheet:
REVIEW
SPEC: DRV8323SRTAR TI WQFN-40 6x6 (RTA) VM 6-60 V rec, 65 V abs max 3x CSA SPI 1 A/2 A gate drive Digital pin abs max 5.75 V (independent of VM) SPx/SNx: +/-1 V continuous, +/-3 V transient 200 ns
DESIGN NOTE: CALC - CHARGE PUMP I_VCP = 3 x Qg(HS) x f_sw = 3 x [FILL] nC x [FILL] kHz = [FILL] mA DRV8323 supplies 25 mA. Margin = [FILL] x.
Motor Driver
Inverter
[${#}] Motor Driver - DRV8323SRTAR
Test Points & Design Notes

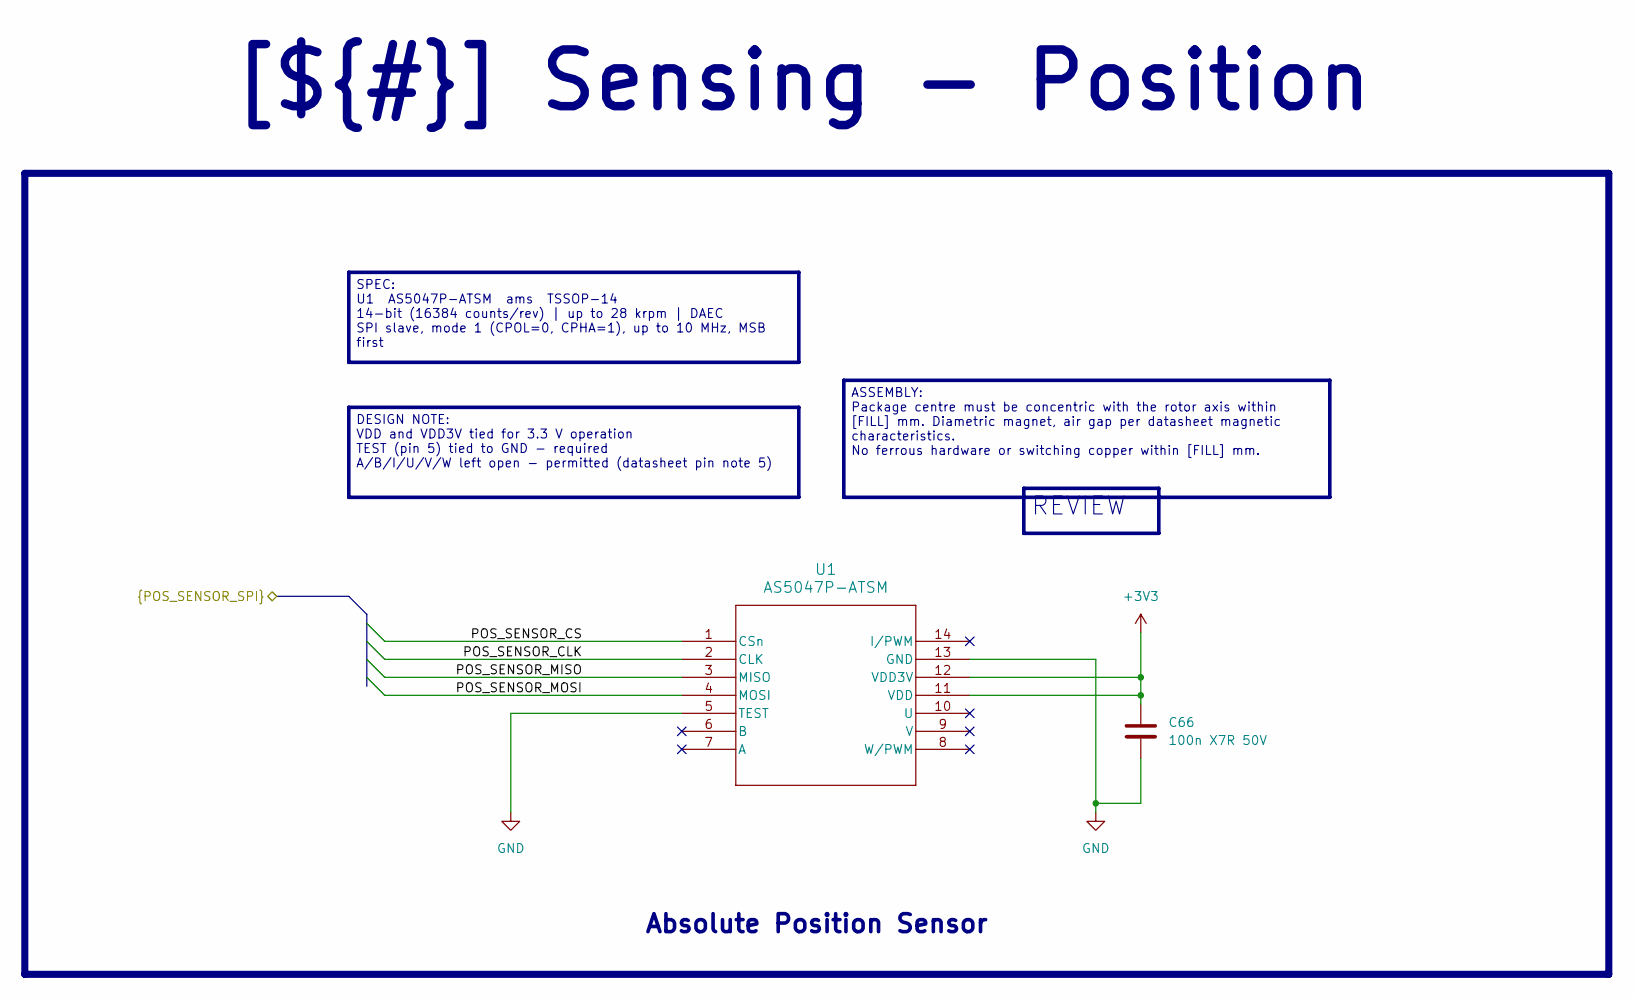
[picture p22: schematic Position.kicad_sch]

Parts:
C66: 100n X7R 50V; C_0402_1005Metric
U1: AS5047P-ATSM; TSSOP14_OSM

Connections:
+3V3: C66.1, U1.11 (VDD), U1.12 (VDD3V); also elsewhere on the board
/Project Architecture/Interface - Interconnects/POS_SENSOR_CLK: U1.2 (CLK); also elsewhere on the board
/Project Architecture/Interface - Interconnects/POS_SENSOR_CS: U1.1 (CSn); also elsewhere on the board
/Project Architecture/Interface - Interconnects/POS_SENSOR_MISO: U1.3 (MISO); also elsewhere on the board
/Project Architecture/Interface - Interconnects/POS_SENSOR_MOSI: U1.4 (MOSI); also elsewhere on the board
GND: C66.2, U1.5 (TEST), U1.13 (GND); also elsewhere on the board

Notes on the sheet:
[${#}] Sensing - Position
Absolute Position Sensor
SPEC: U1 AS5047P-ATSM ams TSSOP-14 14-bit (16384 counts/rev) | up to 28 krpm | DAEC SPI slave, mode 1 (CPOL=0, CPHA=1), up to 10 MHz, MSB first
ASSEMBLY: Package centre must be concentric with the rotor axis within [FILL] mm. Diametric magnet, air gap per datasheet magnetic characteristics. No ferrous hardware or switching copper within [FILL] mm.
DESIGN NOTE: VDD and VDD3V tied for 3.3 V operation TEST (pin 5) tied to GND - required A/B/I/U/V/W left open - permitted (datasheet pin note 5)
REVIEW

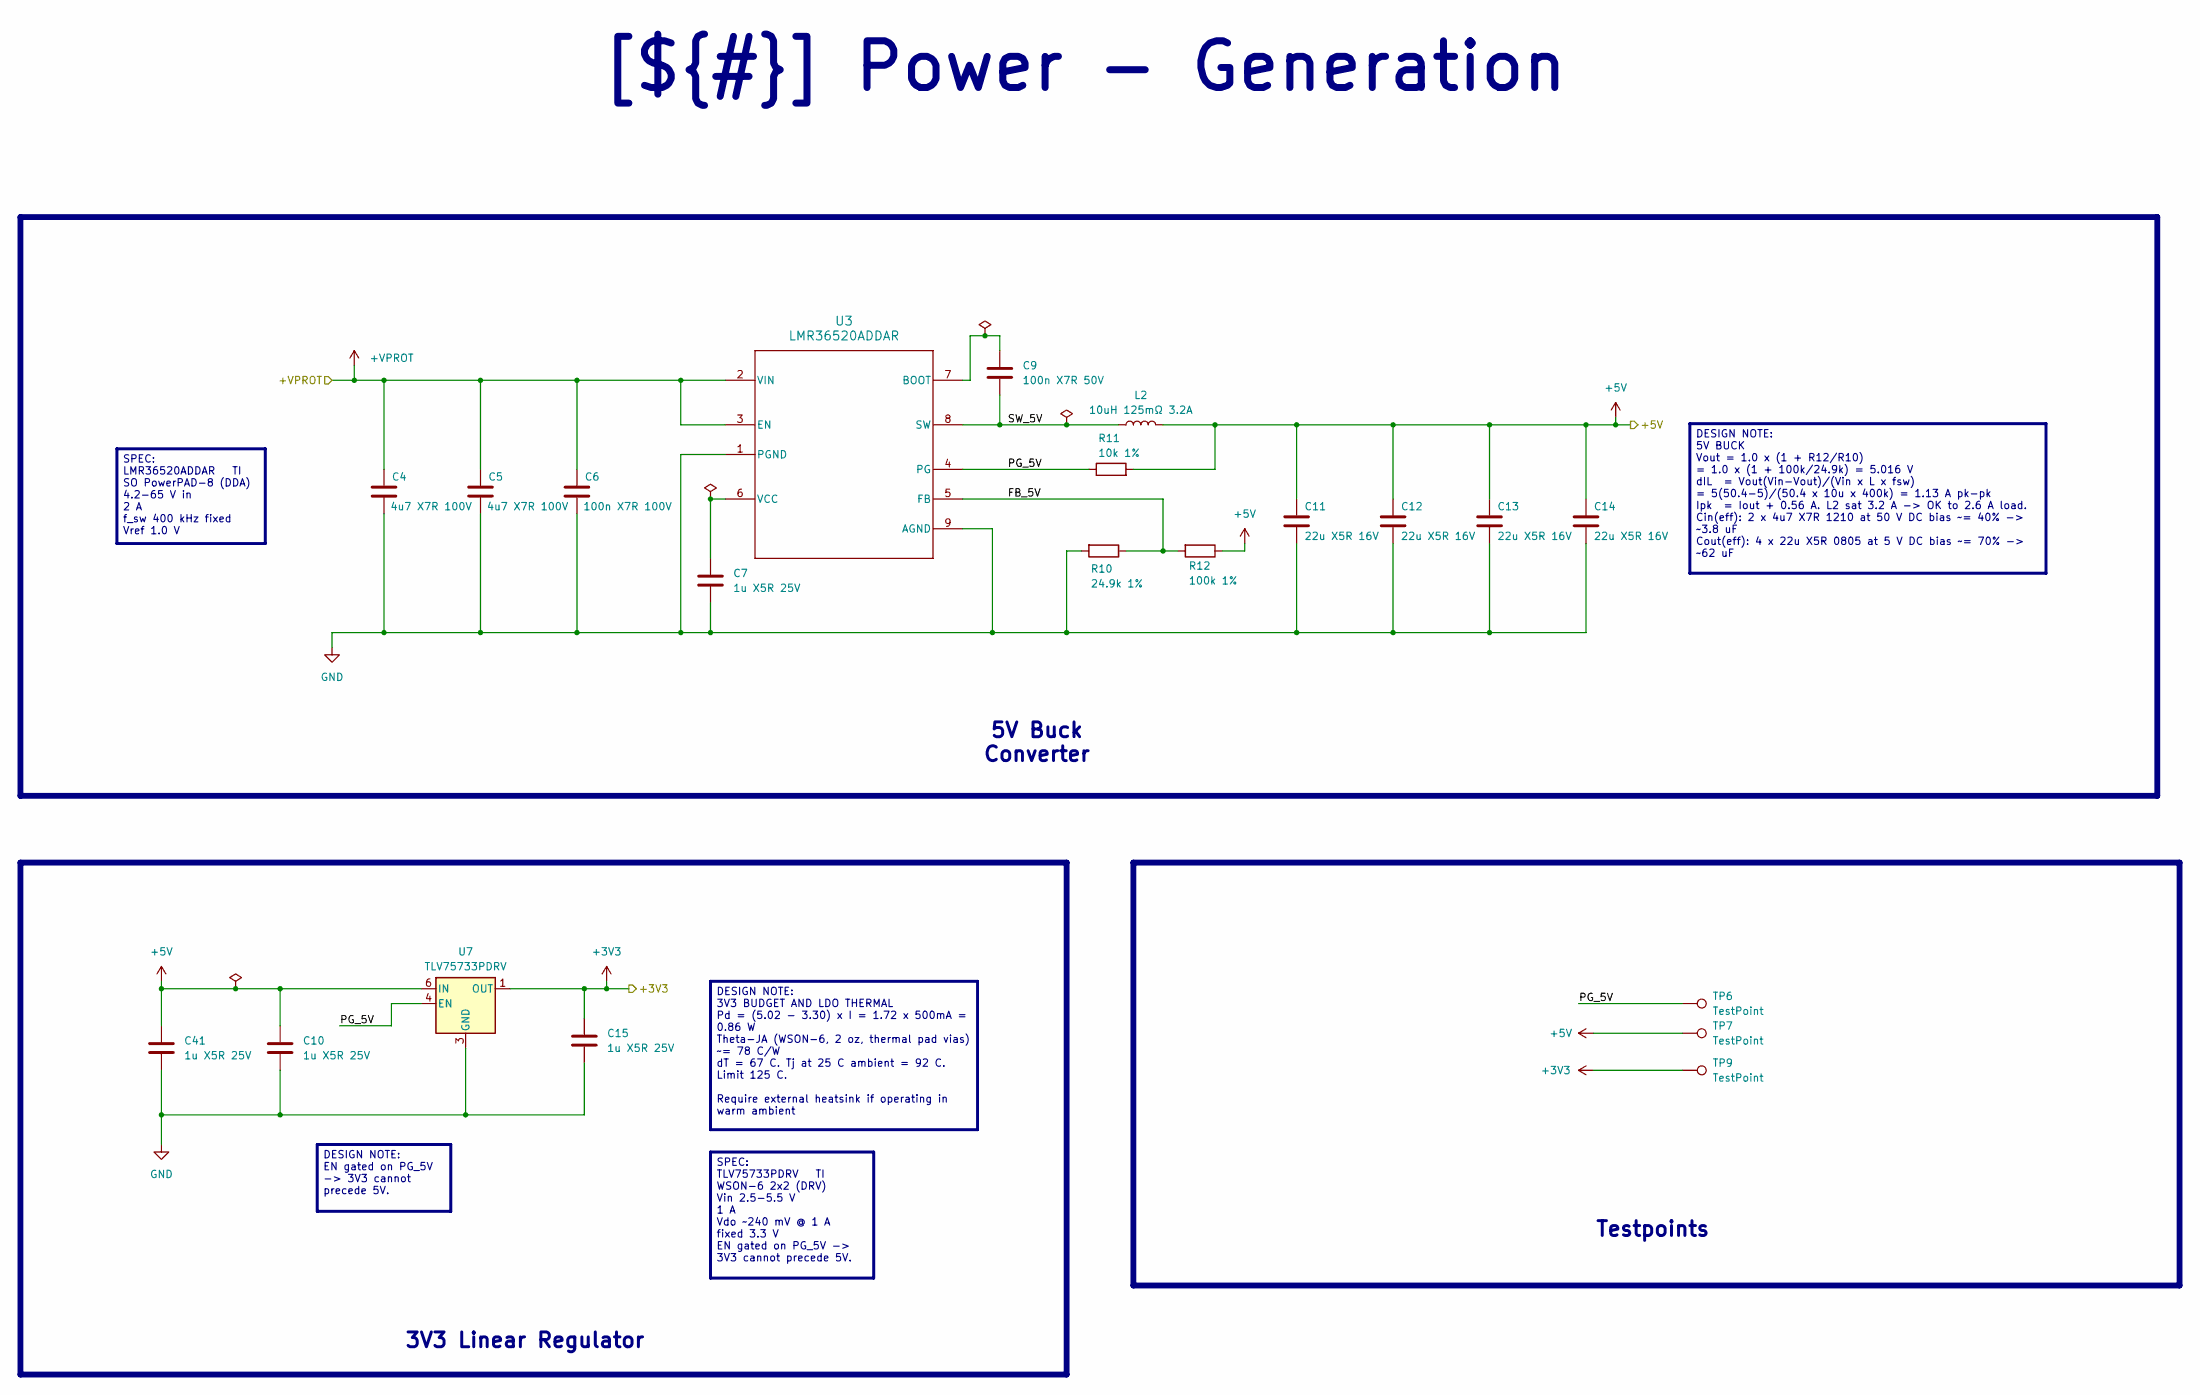
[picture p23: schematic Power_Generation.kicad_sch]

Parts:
C4, C5: 4u7 X7R 100V; C_1210_3225Metric_Pad1.33x2.70mm_HandSolder
C6: 100n X7R 100V; C_0603_1608Metric_Pad1.08x0.95mm_HandSolder
C7, C10, C15, C41: 1u X5R 25V; C_0603_1608Metric
C9: 100n X7R 50V; C_0402_1005Metric
C11, C12, C13, C14: 22u X5R 16V; C_0805_2012Metric
L2: 10uH 125mΩ 3.2A; L_Changjiang_FXL0530
R10: 24.9k 1%; R_0402_1005Metric
R11: 10k 1%; R_0402_1005Metric
R12: 100k 1%; R_0402_1005Metric
TP6, TP7, TP9: TestPoint; TestPoint-0.5mm
U3: LMR36520ADDAR; DDA0008J
U7: TLV75733PDRV; WDFN-6_2x2mm

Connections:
+3V3: C15.1, TP9.1 (1_1), U7.1 (OUT); also elsewhere on the board
+5V: C10.1, C11.1, C12.1, C13.1, C14.1, C41.1, L2.2, R11.2, R12.1, TP7.1 (1_1), U7.6 (IN); also elsewhere on the board
+VPROT: C4.1, C5.1, C6.1, U3.2 (VIN), U3.3 (EN); also elsewhere on the board
/Project Architecture/Power - Generation/FB_5V: R10.1, R12.2, U3.5 (FB)
/Project Architecture/Power - Generation/PG_5V: R11.1, TP6.1 (1_1), U3.4 (PG), U7.4 (EN)
/Project Architecture/Power - Generation/SW_5V: C9.2, L2.1, U3.8 (SW)
GND: C4.2, C5.2, C6.2, C7.2, C10.2, C11.2, C12.2, C13.2, C14.2, C15.2, C41.2, R10.2, U3.1 (PGND), U3.9 (AGND), U7.3 (GND), U7.7 (GND); also elsewhere on the board
unnamed: C9.1, U3.7 (BOOT)
unnamed: C7.1, U3.6 (VCC)

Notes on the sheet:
3V3 Linear Regulator
Testpoints
SPEC: TLV75733PDRV TI WSON-6 2x2 (DRV) Vin 2.5-5.5 V 1 A Vdo ~240 mV @ 1 A fixed 3.3 V EN gated on PG_5V -> 3V3 cannot precede 5V.
DESIGN NOTE: EN gated on PG_5V -> 3V3 cannot precede 5V.
DESIGN NOTE: 5V BUCK Vout = 1.0 x (1 + R12/R10) = 1.0 x (1 + 100k/24.9k) = 5.016 V dIL = Vout(Vin-Vout)/(Vin x L x fsw) = 5(50.4-5)/(50.4 x 10u x 400k) = 1.13 A pk-pk Ipk = Iout + 0.56 A. L2 sat 3.2 A -> OK to 2.6 A load. Cin(eff): 2 x 4u7 X7R 1210 at 50 V DC bias ~= 40% -> ~3.8 uF Cout(eff): 4 x 2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
DESIGN NOTE: 3V3 BUDGET AND LDO THERMAL Pd = (5.02 - 3.30) x I = 1.72 x 500mA = 0.86 W Theta-JA (WSON-6, 2 oz, thermal pad vias) ~= 78 C/W dT = 67 C. Tj at 25 C ambient = 92 C. Limit 125 C. Require external heatsink if operating in warm ambient
5V Buck Converter
[${#}] Power - Generation
SPEC: LMR36520ADDAR TI SO PowerPAD-8 (DDA) 4.2-65 V in 2 A f_sw 400 kHz fixed Vref 1.0 V

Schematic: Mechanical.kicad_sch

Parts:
C73, C74, C75, C76: 1n X7R 1kV; C_0603_1608Metric_Pad1.08x0.95mm_HandSolder
H4, H5, H6, H7: M3_MountingHole_Pad; MountingHole_3.2mm_M3_Pad_Via
R56, R57, R59: 0R 1% 1/8W; R_0805_2012Metric; not fitted
R58: 0R 1% 1/8W; R_0805_2012Metric

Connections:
CHASSIS1: C73.1, H4.1 (1_1), R56.1
CHASSIS2: C74.1, H5.1 (1_1), R57.1
CHASSIS3: C75.1, H6.1 (1_1), R58.1; also elsewhere on the board
CHASSIS4: C76.1, H7.1 (1_1), R59.1
GND: C73.2, C74.2, C75.2, C76.2, R56.2, R57.2, R58.2, R59.2; also elsewhere on the board

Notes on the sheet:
[${#}] Mechanical - Mounting Holes
DESIGN NOTE: 0-Ohmresistor provides low-impedance bond between chassis and signal GND. Be aware of ground loops through cable shield.
DESIGN NOTE: Optional RC filter for chassis grounding. Capacitors offer multi-point low-impedance connections at high-frequencies.

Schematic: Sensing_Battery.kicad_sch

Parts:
C60: 100n X7R 50V; C_0402_1005Metric
R36: 2k 1%; R_0402_1005Metric
R72: 24.9k 1%; R_0402_1005Metric
R73: 12.4k 1%; R_0402_1005Metric

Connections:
+VPROT: R72.1; also elsewhere on the board
/Project Architecture/MCU - IOs/VBAT_SENSE: C60.1, R36.1, R73.2; also elsewhere on the board
GND: C60.2, R36.2; also elsewhere on the board
unnamed: R72.2, R73.1

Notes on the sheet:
Battery Voltage Sensor
[${#}] Sensing - Battery
DESIGN NOTE: Ratio = R36/(R72+R73+R36) = 2/(24.9+12.4+2) = 2/39.3 = 0.05089 at 50.4 V -> 2.565 V at 56.0 V -> 2.850 V clips at VREF+ = 3.3 V when Vbus = 64.8 V Divider current at 50.4 V = 1.283 mA (continuous pack drain) P(R72) = 41 mW, P(R73) = 20 mW Rth = (R72+R73) || R36 = 1.90 k tau = 190 us, f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

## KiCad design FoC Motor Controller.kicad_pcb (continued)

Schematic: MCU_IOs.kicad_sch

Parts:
C16: 22u X5R 16V; C_0805_2012Metric
C17, C20, C24: 1u X5R 25V; C_0603_1608Metric
C18, C19, C21, C22, C23: 100n X7R 50V; C_0402_1005Metric
C25, C26, C27: 2n2 X7R 50V; C_0402_1005Metric
C28, C29: 12pF 50V C0G; C_0402_1005Metric
R13, R14, R15: 56R 1%; R_0402_1005Metric
TP11, TP12, TP13, TP14, TP15, TP16, TP17, TP18, TP19, TP20, TP21, TP22, TP23, TP24, TP25, TP26, TP27, TP28, TP29, TP30, TP31, TP32, TP33, TP34, TP35, TP36: TestPoint; TestPoint-0.5mm
U5: STM32G431RBTx; LQFP-64_10x10mm_P0.5mm
X1: SMD3225-4; Crystal_SMD_3225-4Pin_3.2x2.5mm

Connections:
+3V3: C16.1, C17.1, C18.1, C19.1, C20.1, C21.1, C22.1, C23.1, C24.1, U5.1 (VBAT), U5.16 (VDD), U5.28 (VREF+), U5.29 (VDDA), U5.32 (VDD), U5.48 (VDD), U5.64 (VDD); also elsewhere on the board
/Project Architecture/Interface - CAN FD/FDCAN_RX: TP12.1 (1_1), U5.61 (PB8); also elsewhere on the board
/Project Architecture/Interface - CAN FD/FDCAN_TX: TP11.1 (1_1), U5.62 (PB9); also elsewhere on the board
/Project Architecture/Interface - Interconnects/I2C3_SCL: U5.40 (PC8); also elsewhere on the board
/Project Architecture/Interface - Interconnects/I2C3_SDA: U5.41 (PC9); also elsewhere on the board
/Project Architecture/Interface - Interconnects/NRST: U5.7 (PG10); also elsewhere on the board
/Project Architecture/Interface - Interconnects/POS_SENSOR_CLK: U5.19 (PA5); also elsewhere on the board
/Project Architecture/Interface - Interconnects/POS_SENSOR_CS: U5.18 (PA4); also elsewhere on the board
/Project Architecture/Interface - Interconnects/POS_SENSOR_CS2: U5.22 (PC4); also elsewhere on the board
/Project Architecture/Interface - Interconnects/POS_SENSOR_MISO: U5.20 (PA6); also elsewhere on the board
/Project Architecture/Interface - Interconnects/POS_SENSOR_MOSI: U5.21 (PA7); also elsewhere on the board
/Project Architecture/Interface - Interconnects/SWCLK: U5.50 (PA14); also elsewhere on the board
/Project Architecture/Interface - Interconnects/SWDIO: U5.49 (PA13); also elsewhere on the board
/Project Architecture/Interface - Interconnects/UART1_RX: TP14.1 (1_1), U5.59 (PB6); also elsewhere on the board
/Project Architecture/Interface - Interconnects/UART1_TX: TP13.1 (1_1), U5.60 (PB7); also elsewhere on the board
/Project Architecture/MCU - IOs/DRV_CAL: TP29.1 (1_1), U5.38 (PC6); also elsewhere on the board
/Project Architecture/MCU - IOs/DRV_CS: TP33.1 (1_1), U5.55 (PD2); also elsewhere on the board
/Project Architecture/MCU - IOs/DRV_ENABLE: TP28.1 (1_1), U5.39 (PC7); also elsewhere on the board
/Project Architecture/MCU - IOs/DRV_MISO: TP30.1 (1_1), U5.53 (PC11); also elsewhere on the board
/Project Architecture/MCU - IOs/DRV_MOSI: TP31.1 (1_1), U5.54 (PC12); also elsewhere on the board
/Project Architecture/MCU - IOs/DRV_SCLK: TP32.1 (1_1), U5.52 (PC10); also elsewhere on the board
/Project Architecture/MCU - IOs/DRV_nFAULT: TP27.1 (1_1), U5.51 (PA15); also elsewhere on the board
/Project Architecture/MCU - IOs/FILTER_SOA: C27.1, R15.1, TP17.1 (1_1), U5.33 (PB11)
/Project Architecture/MCU - IOs/FILTER_SOB: C26.1, R14.1, TP16.1 (1_1), U5.34 (PB12)
/Project Architecture/MCU - IOs/FILTER_SOC: C25.1, R13.1, TP15.1 (1_1), U5.36 (PB14)
/Project Architecture/MCU - IOs/MCU_LED: U5.58 (PB5); also elsewhere on the board
/Project Architecture/MCU - IOs/MOT_TEMP_SENSE: TP36.1 (1_1), U5.26 (PB2); also elsewhere on the board
/Project Architecture/MCU - IOs/OSC_IN: C29.1, U5.5 (PF0), X1.1
/Project Architecture/MCU - IOs/OSC_OUT: C28.1, U5.6 (PF1), X1.3
/Project Architecture/MCU - IOs/PA0: U5.12 (PA0)
/Project Architecture/MCU - IOs/PA1: U5.13 (PA1)
/Project Architecture/MCU - IOs/PA2: U5.14 (PA2)
/Project Architecture/MCU - IOs/PA3: U5.17 (PA3)
/Project Architecture/MCU - IOs/PB3: U5.56 (PB3)
/Project Architecture/MCU - IOs/PB10: U5.30 (PB10)
/Project Architecture/MCU - IOs/PB13: U5.35 (PB13)
/Project Architecture/MCU - IOs/PC0: U5.8 (PC0)
/Project Architecture/MCU - IOs/PC1: U5.9 (PC1)
/Project Architecture/MCU - IOs/PC2: U5.10 (PC2)
/Project Architecture/MCU - IOs/PC3: U5.11 (PC3); also elsewhere on the board
/Project Architecture/MCU - IOs/PC5: U5.23 (PC5)
/Project Architecture/MCU - IOs/PC13: U5.2 (PC13)
/Project Architecture/MCU - IOs/PC14: U5.3 (PC14)
/Project Architecture/MCU - IOs/PC15: U5.4 (PC15)
/Project Architecture/MCU - IOs/PWM_PHASEA_H: TP21.1 (1_1), U5.42 (PA8); also elsewhere on the board
/Project Architecture/MCU - IOs/PWM_PHASEA_L: TP22.1 (1_1), U5.45 (PA11); also elsewhere on the board
/Project Architecture/MCU - IOs/PWM_PHASEB_H: TP23.1 (1_1), U5.43 (PA9); also elsewhere on the board
/Project Architecture/MCU - IOs/PWM_PHASEB_L: TP24.1 (1_1), U5.46 (PA12); also elsewhere on the board
/Project Architecture/MCU - IOs/PWM_PHASEC_H: TP25.1 (1_1), U5.44 (PA10); also elsewhere on the board
/Project Architecture/MCU - IOs/PWM_PHASEC_L: TP26.1 (1_1), U5.37 (PB15); also elsewhere on the board
/Project Architecture/MCU - IOs/PWR_LED: U5.57 (PB4); also elsewhere on the board
/Project Architecture/MCU - IOs/SOA: R15.2, TP20.1 (1_1); also elsewhere on the board
/Project Architecture/MCU - IOs/SOB: R14.2, TP19.1 (1_1); also elsewhere on the board
/Project Architecture/MCU - IOs/SOC: R13.2, TP18.1 (1_1); also elsewhere on the board
/Project Architecture/MCU - IOs/TEMP_SENSE: TP35.1 (1_1), U5.25 (PB1); also elsewhere on the board
/Project Architecture/MCU - IOs/VBAT_SENSE: TP34.1 (1_1), U5.24 (PB0); also elsewhere on the board
GND: C16.2, C17.2, C18.2, C19.2, C20.2, C21.2, C22.2, C23.2, C24.2, C25.2, C26.2, C27.2, C28.2, C29.2, U5.15 (VSS), U5.27 (VSSA), U5.31 (VSS), U5.47 (VSS), U5.63 (VSS), X1.2, X1.4; also elsewhere on the board

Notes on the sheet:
SWD
DESIGN NOTE: CALC - CRYSTAL LOAD CL = (C28 x C29)/(C28 + C29) + Cstray = (12 x 12)/24 + ~5 = 11 pF Selected a crystal specified for CL = 11-12 pF.
Analog IO
REVIEW
[${#}] MCU - IOs
SPEC: ADC CHANNEL MAP FILTER_SOA PB11 ADC1_IN14 / ADC2_IN14 (both) FILTER_SOB PB12 ADC1_IN11 (ADC1 only) FILTER_SOC PB14 ADC1_IN5 (ADC1 only) VBAT_SENSE PB0 ADC1_IN15 TEMP_SENSE PB1 ADC1_IN12 MOT_TEMP PB2 ADC2_IN12 Simultaneous dual-ADC sampling MUST pair SOA (on ADC2) with SOB or SOC (on ADC1). Ph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
MCU - STM32G431RBT6
FIRMWARE - MANDATORY AT BOOT 1. Program nSWBOOT0 = 0 so BOOT0 comes from the option bit, not PB8 (PB8 = FDCAN1_RX). 2. Set PWR_CR3.UCPD1_DBDIS = 1 BEFORE enabling TIM1. PA9/PA10 (PWM_PHASEB_H / PWM_PHASEC_H) are UCPD1_DBCC1/2. A high level enables internal 5.1k pull-downs on PB6 (UART TX) and PB4 (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
Testpoints
Digital IO

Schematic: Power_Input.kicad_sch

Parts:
D1: SMCJ51CA; D_SMC_TVS
H8, H9: Power; MountingHole_3.2mm_M3_Pad_Via

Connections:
+VPROT: D1.2 (A), H8.1 (1_1); also elsewhere on the board
GND: D1.1 (K), H9.1 (1_1); also elsewhere on the board

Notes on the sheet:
ACCEPTED RISK: D1 clamps at 82.4 V. Downstream absolute maximums: DRV8323 VM/VDRAIN 65 V LMR36520 VIN 65 V TLV75733 VIN 5.5 V (fed from +5V, not exposed) D1 therefore does NOT protect the board against an event large enough to engage it. SOLUTION: Upstream PDB handles protection
ASSEMBLY: D3.2mm solder pad, no connector
SPEC: SMCJ51CA Littelfuse SMC / DO-214AB Vrwm 51 V Vbr(min) 56.7 V Vclamp 82.4 V @ 18.2 A 1500 W Bidirectional (CA suffix)
Input Power
[${#}] Power - Input

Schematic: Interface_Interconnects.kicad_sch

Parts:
C42: 2n2 X7R 50V; C_0402_1005Metric
C67, C70, C72, C78, C81: 100n X7R 50V; C_0402_1005Metric
C68: 47n X7R 100V; C_0603_1608Metric_Pad1.08x0.95mm_HandSolder
D4, D7: PESD2CANFD24V-K; TVS_PESD2CANFD24V-UX; PARTREV V.4
J1, J3, J4, J5: Conn_01x04_MountingPin; JST_GH_BM04B-GHS-TBT_1x04-1MP_P1.25mm_Vertical
J2: Conn_01x03; 1x03_P2.54mm; not fitted
J6: Conn_01x07_MountingPin; JST_GH_BM07B-GHS-TBT_1x07-1MP_P1.25mm_Vertical
J7: Conn_01x05; PinHeader_1x05_P2.54mm_Vertical
J10, J11: Conn_01x02_MountingPin; JST_GH_BM02B-GHS-TBT_1x02-1MP_P1.25mm_Vertical
R41: 1k 1%; R_0402_1005Metric
R42, R44: 2k 1%; R_0402_1005Metric
R45, R46: 60R4 1%; R_0805_2012Metric
R47, R48, R49, R50, R51, R52, R53, R54: 100R 1%; R_0402_1005Metric
SW1: SW_Push_DPDT; Slide_DPDT_SMD_7.2x3.5mm

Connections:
+3V3: C72.1, C78.1, C81.1, J1.2, J3.2, J6.2, J7.1, R42.1, R44.1; also elsewhere on the board
+5V: C70.1, J6.1; also elsewhere on the board
/Project Architecture/Interface - CAN FD/FDCAN_N: D4.2, D7.2, J2.1, J4.2, J5.2, SW1.4 (A); also elsewhere on the board
/Project Architecture/Interface - CAN FD/FDCAN_P: D4.1, D7.1, J2.2, J4.3, J5.3, SW1.1 (A); also elsewhere on the board
/Project Architecture/Interface - Interconnects/AUX2_A: J6.4, R47.1
/Project Architecture/Interface - Interconnects/AUX2_B: J6.5, R49.1
/Project Architecture/Interface - Interconnects/AUX2_C: J6.6, R51.1
/Project Architecture/Interface - Interconnects/AUX2_D: J6.7, R53.1
/Project Architecture/Interface - Interconnects/FDCAN_TERM_B: R46.2, SW1.5 (B)
/Project Architecture/Interface - Interconnects/FDCAN_TERM_MID: C68.1, R45.2, R46.1
/Project Architecture/Interface - Interconnects/FDCAN_TERM_T: R45.1, SW1.2 (B)
/Project Architecture/Interface - Interconnects/I2C3_SCL: R44.2, R50.2; also elsewhere on the board
/Project Architecture/Interface - Interconnects/I2C3_SDA: R42.2, R48.2; also elsewhere on the board
/Project Architecture/Interface - Interconnects/MOT_NTC_H: J10.1; also elsewhere on the board
/Project Architecture/Interface - Interconnects/MOT_NTC_L: J10.2; also elsewhere on the board
/Project Architecture/Interface - Interconnects/NRST: C67.1, J7.2; also elsewhere on the board
/Project Architecture/Interface - Interconnects/POS_SENSOR_CLK: R49.2; also elsewhere on the board
/Project Architecture/Interface - Interconnects/POS_SENSOR_CS2: R47.2; also elsewhere on the board
/Project Architecture/Interface - Interconnects/POS_SENSOR_MISO: R51.2; also elsewhere on the board
/Project Architecture/Interface - Interconnects/POS_SENSOR_MOSI: R53.2; also elsewhere on the board
/Project Architecture/Interface - Interconnects/SWCLK: J7.3; also elsewhere on the board
/Project Architecture/Interface - Interconnects/SWDIO: J7.4; also elsewhere on the board
/Project Architecture/Interface - Interconnects/UART1_RX: R54.2; also elsewhere on the board
/Project Architecture/Interface - Interconnects/UART1_TX: R52.2; also elsewhere on the board
/Project Architecture/MCU - IOs/DRV_ENABLE: C42.1, J11.1, R41.1; also elsewhere on the board
/Project Architecture/MCU - IOs/PC3: R41.2; also elsewhere on the board
CHASSIS3: D4.3, D7.3; also elsewhere on the board
GND: C42.2, C67.2, C68.2, C70.2, C72.2, C78.2, C81.2, J1.1, J2.3, J3.1, J4.4, J5.4, J6.3, J7.5, J11.2; also elsewhere on the board
unnamed: J1.3, R52.1
unnamed: J1.4, R54.1
unnamed: J3.3, R48.1
unnamed: J3.4, R50.1

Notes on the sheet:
DESIGN NOTE: Loop closed = PC3 low = run; Loop open OR cable unplugged = PC3 high = hardware break.
DESIGN NOTE: J6 shares SPI1 (SCK/MISO/MOSI) with the on-board AS5047P (U1). Isolation is by chip select only: U1 on PA4, remote on PC4. AS5047P tri-states MISO when CSn is high (datasheet t_OZ), so two slaves on one bus is valid - but firmware MUST NOT assert both chip selects.
SWD (2.54mm Pin Header)
AUX2 Connector (Position Sensor SPI)
DESIGN NOTE: No ESD protection for prototype. Expected to be in lab environment.
Temperature
DESIGN NOTE: UART PIN NAMING Net UART1_TX lands on PB7 = USART1_RX. Net UART1_RX lands on PB6 = USART1_TX.
[${#}] Interface - Interconnects
FD_CAN Connectors and Termination

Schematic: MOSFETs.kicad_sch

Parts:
C34, C37, C39: 100uF 100V; CP_Radial_D10.0mm_P5.00mm; Voltage 1kV; Tolerance 100%
C35, C36, C45, C46, C56, C57: 2n2 X7R 100V; C_0805_2012Metric; not fitted
C38, C49, C58: 100n X7R 100V; C_0603_1608Metric_Pad1.08x0.95mm_HandSolder
C40, C43, C44, C47, C48, C50, C51, C52, C59: 4u7 X7R 100V; C_1210_3225Metric_Pad1.33x2.70mm_HandSolder
H1, H2, H3: Phase; MountingHole_3.2mm_M3_Pad_Via
NT1, NT2, NT3, NT4, NT5, NT6, NT7, NT8, NT9: NetTie_2; NetTie-2_SMD_Pad0.5mm
Q3, Q4, Q5, Q6, Q7, Q8: ISC030N10NM6; IFX-PG-TDSON-8-36-V
R20, R21, R25, R26, R30, R31: 0R 1% 1/8W; R_0805_2012Metric_Pad1.20x1.40mm_HandSolder
R22, R27, R32: 3mΩ 3W 1%; R_2512_6332Metric_Pad1.40x3.35mm_HandSolder
R23, R24, R28, R29, R33, R34: 3R9 1% 1/8W; R_0805_2012Metric_Pad1.20x1.40mm_HandSolder; not fitted

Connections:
+VPROT: C34.1, C37.1, C38.1, C39.1, C40.1, C43.1, C44.1, C47.1, C48.1, C49.1, C50.1, C51.1, C52.1, C58.1, C59.1, Q3.5 (DRAIN), Q3.6 (DRAIN), Q3.7 (DRAIN), Q3.8 (DRAIN), Q5.5 (DRAIN), Q5.6 (DRAIN), Q5.7 (DRAIN), Q5.8 (DRAIN), Q7.5 (DRAIN), Q7.6 (DRAIN), Q7.7 (DRAIN), Q7.8 (DRAIN), R23.1, R28.1, R33.1; also elsewhere on the board
/Project Architecture/Motor Control - Driver/GHA: R20.2; also elsewhere on the board
/Project Architecture/Motor Control - Driver/GHB: R25.2; also elsewhere on the board
/Project Architecture/Motor Control - Driver/GHC: R30.2; also elsewhere on the board
/Project Architecture/Motor Control - Driver/GLA: R21.2; also elsewhere on the board
/Project Architecture/Motor Control - Driver/GLB: R26.2; also elsewhere on the board
/Project Architecture/Motor Control - Driver/GLC: R31.2; also elsewhere on the board
/Project Architecture/Motor Control - Driver/MOSFETs/GH_A: Q3.4 (GATE), R20.1
/Project Architecture/Motor Control - Driver/MOSFETs/GH_B: Q5.4 (GATE), R25.1
/Project Architecture/Motor Control - Driver/MOSFETs/GH_C: Q7.4 (GATE), R30.1
/Project Architecture/Motor Control - Driver/MOSFETs/GL_A: Q4.4 (GATE), R21.1
/Project Architecture/Motor Control - Driver/MOSFETs/GL_B: Q6.4 (GATE), R26.1
/Project Architecture/Motor Control - Driver/MOSFETs/GL_C: Q8.4 (GATE), R31.1
/Project Architecture/Motor Control - Driver/MOSFETs/OUT_A: C35.2, C36.1, H1.1 (1_1), NT3.2, Q3.1 (SOURCE), Q3.2 (SOURCE), Q3.3 (SOURCE), Q4.5 (DRAIN), Q4.6 (DRAIN), Q4.7 (DRAIN), Q4.8 (DRAIN)
/Project Architecture/Motor Control - Driver/MOSFETs/OUT_B: C45.2, C46.1, H2.1 (1_1), NT6.2, Q5.1 (SOURCE), Q5.2 (SOURCE), Q5.3 (SOURCE), Q6.5 (DRAIN), Q6.6 (DRAIN), Q6.7 (DRAIN), Q6.8 (DRAIN)
/Project Architecture/Motor Control - Driver/MOSFETs/OUT_C: C56.2, C57.1, H3.1 (1_1), NT9.2, Q7.1 (SOURCE), Q7.2 (SOURCE), Q7.3 (SOURCE), Q8.5 (DRAIN), Q8.6 (DRAIN), Q8.7 (DRAIN), Q8.8 (DRAIN)
/Project Architecture/Motor Control - Driver/MOSFETs/RSHUNT_N_A: NT2.1; also elsewhere on the board
/Project Architecture/Motor Control - Driver/MOSFETs/RSHUNT_N_B: NT5.1; also elsewhere on the board
/Project Architecture/Motor Control - Driver/MOSFETs/RSHUNT_N_C: NT8.1; also elsewhere on the board
/Project Architecture/Motor Control - Driver/MOSFETs/RSHUNT_P_A: NT1.1; also elsewhere on the board
/Project Architecture/Motor Control - Driver/MOSFETs/RSHUNT_P_B: NT4.1; also elsewhere on the board
/Project Architecture/Motor Control - Driver/MOSFETs/RSHUNT_P_C: NT7.1; also elsewhere on the board
/Project Architecture/Motor Control - Driver/MOSFETs/SOURCE_A: C38.2, NT1.2, Q4.1 (SOURCE), Q4.2 (SOURCE), Q4.3 (SOURCE), R22.1, R24.2
/Project Architecture/Motor Control - Driver/MOSFETs/SOURCE_B: C49.2, NT4.2, Q6.1 (SOURCE), Q6.2 (SOURCE), Q6.3 (SOURCE), R27.1, R29.2
/Project Architecture/Motor Control - Driver/MOSFETs/SOURCE_C: C58.2, NT7.2, Q8.1 (SOURCE), Q8.2 (SOURCE), Q8.3 (SOURCE), R32.1, R34.2
/Project Architecture/Motor Control - Driver/SHA: NT3.1; also elsewhere on the board
/Project Architecture/Motor Control - Driver/SHB: NT6.1; also elsewhere on the board
/Project Architecture/Motor Control - Driver/SHC: NT9.1; also elsewhere on the board
GND: C34.2, C37.2, C39.2, C40.2, C43.2, C44.2, C47.2, C48.2, C50.2, C51.2, C52.2, C59.2, NT2.2, NT5.2, NT8.2, R22.2, R27.2, R32.2; also elsewhere on the board
unnamed: C35.1, R23.2
unnamed: C36.2, R24.1
unnamed: C45.1, R28.2
unnamed: C46.2, R29.1
unnamed: C56.1, R33.2
unnamed: C57.2, R34.1

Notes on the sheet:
[${#}] MOSFETs
SPEC: Q3-Q8 ISC030N10NM6 Infineon TOLL (PG-HSOF-8) 100 V 3.0 mR typ @ 10 V Qg [FILL] nC Qgd [FILL] nC
DESIGN NOTE: CALC - DC LINK Bulk 3 x 100 uF = 300 uF (polymer, negligible DC derating) MLCC 9 x 4u7 = 42.3 uF nominal at 50 V DC bias, 1210 X7R ~= 0.4 -> 16.9 uF effective Bus ripple dV ~= Idc/(fsw x C) = [FILL]/( [FILL] x 316u) = [FILL] V Ripple current requirement: [FILL] A RMS vs 3 x [FILL] A ra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
REVIEW
DESIGN NOTE: CALC - CONDUCTION LOSS Rds(on) at Tj 125 C ~= 3.0 mR x 1.5 = 4.5 mR P_cond = 3 x Iph_rms^2 x Rds(on) = 3 x [FILL]^2 x 4.5 mR = [FILL] W Shunt P = Iph_rms^2 x 3 mR = [FILL] W each (3 W rated) Vsense at 20 A = 60 mV
DESIGN NOTE: CALC - CURRENT SENSE Rshunt = 3 mR, bidirectional, VREF = 3.3 V, zero at 1.65 V Gain 5 -> +/-110 A Gain 20 -> +/-27.5 A Gain 10 -> +/-55 A Gain 40 -> +/-13.75 A SELECTED: gain 20 V/V ADC resolution at gain 20: (3.3/4096) / 20 / 3 mR = 13.4 mA per LSB Vsense at 20 A = 60 mV (within +/-1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

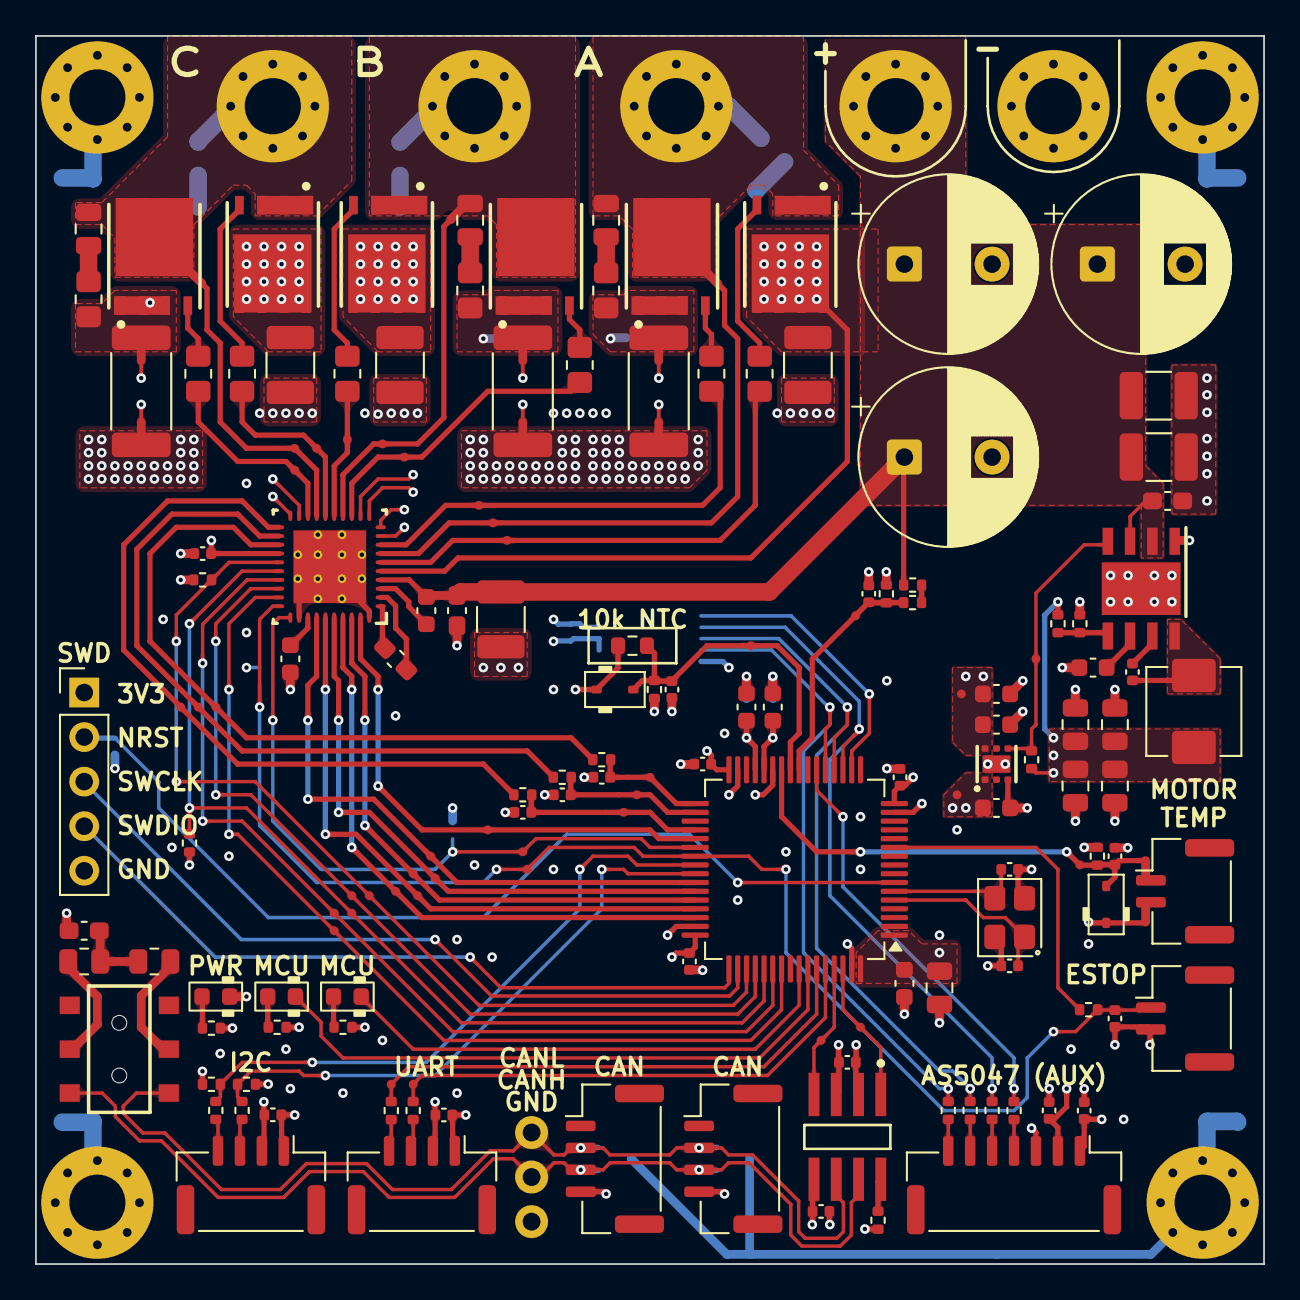
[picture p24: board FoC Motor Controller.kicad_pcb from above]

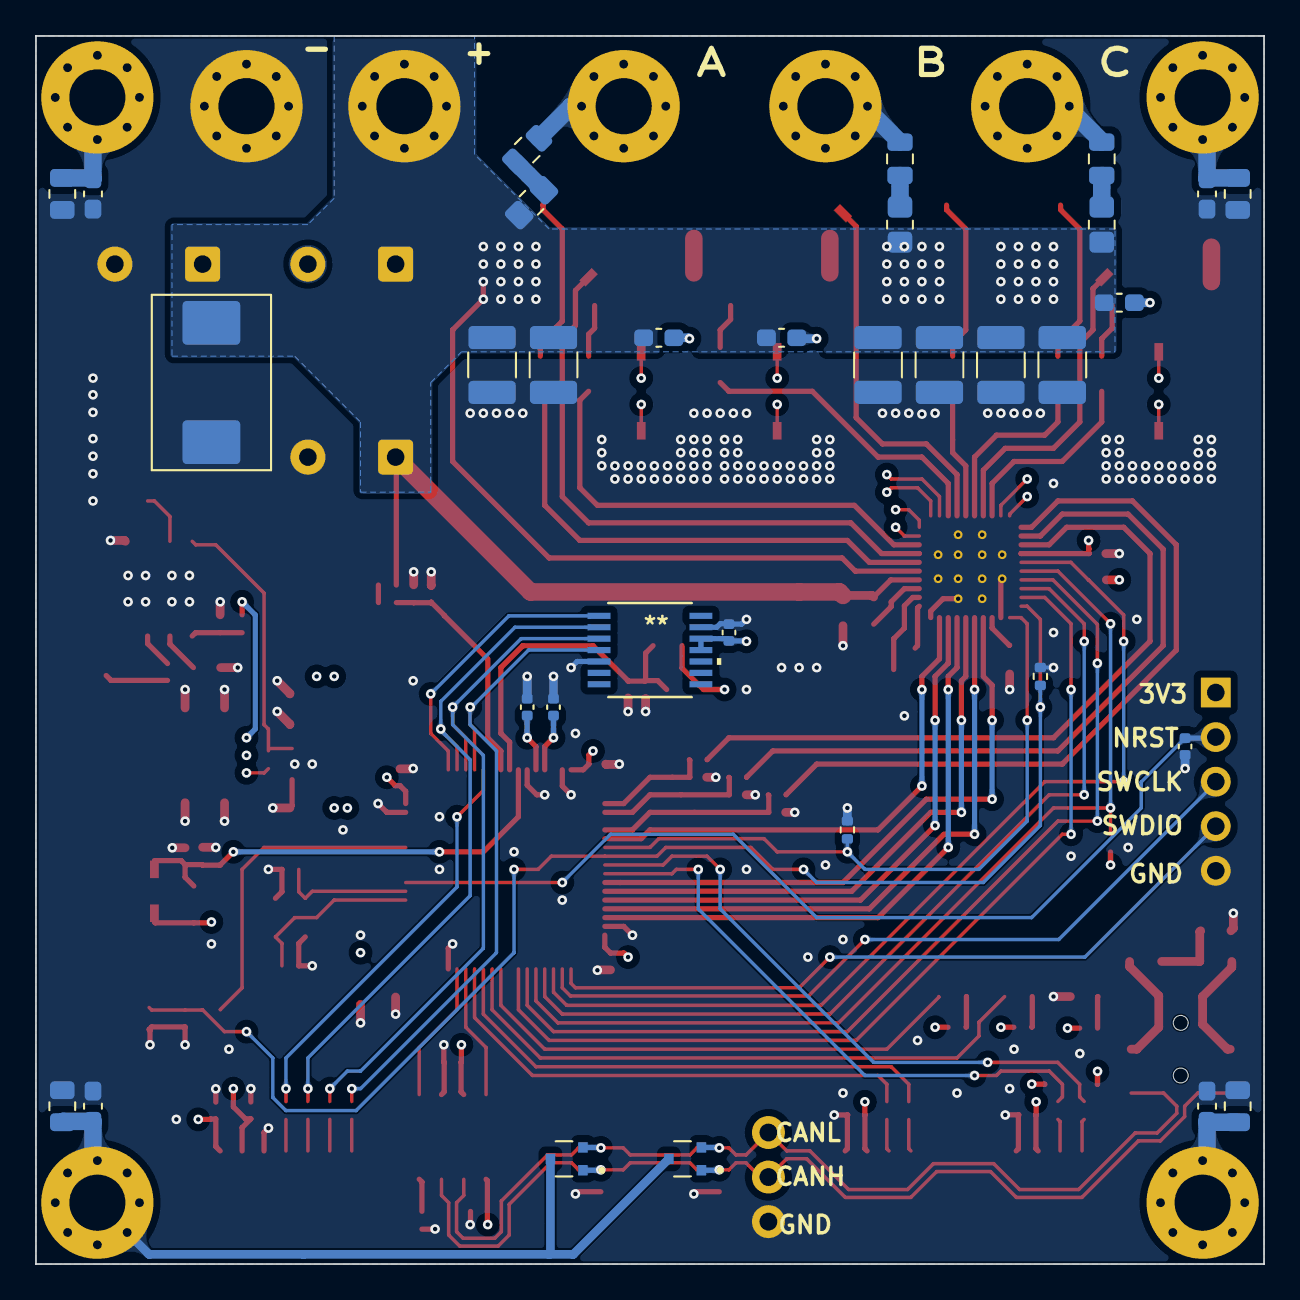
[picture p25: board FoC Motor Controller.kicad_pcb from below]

Board: 6 copper layers, 70.0 x 70.0 mm, 212 parts (33 on the bottom side), 111 nets.

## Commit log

2026-07-27 Initial commit: baseline schematic and PCB
    [Block Diagram.kicad_sch, DRV8323SRTAR_Motor_Driver.kicad_sch, FoC Motor Controller.kicad_pcb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]
2026-09-24 Reorganize project into Altium-style folder structure; add README
    - Move hierarchical sheets to Schematics/, lib/ -> Libraries/,
    Manufacturing/ -> Project Outputs/ (BOM, Assembly, Netlist,
    Fabrication, PDF), LTspice benches -> Simulation/
    - Update Sheetfile, ${KIPRJMOD} library/3D-model, and output paths
    - Drop unused sheets, datasheets, templates and KiCad local history
    from the tracked tree (kept locally, now in .gitignore)
    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
    [Block Diagram.kicad_sch, DRV8323SRTAR_Motor_Driver.kicad_sch, FoC Motor Controller.kicad_pcb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]
2026-10-16 Clean up schematic design notes; export schematic and PCB artwork PDFs
    - Remove firmware-only notes (boot sequence, calibration procedure,
    firmware SPI/PWM settings) and template/empty text; keep hardware facts
    - Tighten wording of all DESIGN/SPEC/ASSEMBLY/REV 1 notes and resize
    boxes so no note text wraps or overflows
    - Re-export schematic PDF
    - Add PCB artwork PDFs (combined and one per layer: silk, paste, mask,
    L1-L6 copper), board outline on every page
2026-10-29 README: update status -- Rev 1 partly bench-validated at 12 V
2026-10-30 Simulation: LTspice bench-correlation suite with DHO804 bench results
    Replace the old Simulation/LTspice_* benches with a three-deck suite built
    from the Rev 1 netlist and the firmware-measured MN601-S constants, each
    paired with bench captures from the DHO804:
    - 01_hot_plug: XT60 hot-plug at 30 V. Bench (runs 4-5): peak 30.15 V, no
    overshoot; charge is limited by the KA3005P (tau ~6.5 ms), not the ideal
    source the deck assumes.
    - 02_leg_switching: half-bridge edge. Bench at 12 V / ID_R 0.8 A (the
    approved switching scope) vs 02b variant: rise 8.8 ns = sim 7.0 ns through
    the 70 MHz scope; overshoot below the sim.
    - 03_standstill_csa: CSA chain. Bench via I/f spin 2 A / 300 rpm vs 03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
